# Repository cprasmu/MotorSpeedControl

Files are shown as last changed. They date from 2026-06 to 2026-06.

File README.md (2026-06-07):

# ESP32 Motor Speed Control with L298N and IR Sensor

This project uses a motor & gears from a Microsoft Sidewinder force feedback wheels and an ESP32 to control a DC motor via an L298N H-Bridge, reads rotation speed from an IR sensor connected to a slotted wheel on the motor shaft, and serves a simple web interface to control motor direction and speed. The system accounts for an 11-slot encoder wheel and a 35:1 gearbox reduction to display the actual output shaft RPM. Additionally, it features a TFT display for real-time monitoring and an IR remote for wireless control.

## Features

- Continuous motor control (direction and speed) via web interface
- Precise position control: rotate output shaft exactly one turn clockwise or counterclockwise
- Real-time RPM display of output shaft (after gearbox reduction)
- WiFi access point for easy connection
- Real-time monitoring via TFT display (speed, gear ratio, RPM, direction)
- Wireless control using IR remote (Apple protocol) for motor direction, speed, and preset turns

## Hardware Connections

### L298N H-Bridge
- **IN1** -> ESP32 GPIO 27
- **IN2** -> ESP32 GPIO 26
- **ENA** (PWM speed control) -> ESP32 GPIO 25
- **GND** -> ESP32 GND
- **Motor power supply** -> Connect to appropriate voltage (e.g., 12V) and GND common with ESP32

### IR Sensor
- **Output** -> ESP32 GPIO 33 (with interrupt)
- **VCC** -> 3.3V or 5V (depending on sensor)
- **GND** -> GND

### Motor
- Connect motor terminals to L298N output terminals (OUT1 and OUT2)

### TFT Display
- **TFT MOSI** -> ESP32 GPIO 19
- **TFT SCLK** -> ESP32 GPIO 18
- **TFT CS** -> ESP32 GPIO 5
- **TFT DC** -> ESP32 GPIO 16
- **TFT RST** -> ESP32 GPIO 23
- **TFT BL** (backlight) -> ESP32 GPIO 4

### IR Remote
- **IR Receiver OUT** -> ESP32 GPIO 32

## Setup

1. Install the ESP32 board in Arduino IDE:
   - Go to File > Preferences
   - Add `https://raw.githubusercontent.com/espressif/arduino-esp32/gh-pages/package_esp32_index.json` to Additional Boards Manager URLs
   - Go to Tools > Board > Boards Manager, search for ESP32 and install

2. Install the required libraries:
   - TFT_eSPI (by Bodmer) - Make sure to copy the provided User_Setup.h to the TFT_eSPI library folder or modify your own to match the pins defined in the code.
   - IRremote (by Armin Joachimsmeyer)

3. Connect your ESP32 to the computer via USB.

4. Select the correct ESP32 board (e.g., "ESP32 Dev Module") and port.

5. Upload the `main.ino` sketch.

6. After uploading, open the Serial Monitor to see the IP address of the ESP32 access point.

7. Connect your computer or phone to the WiFi network:
   - SSID: `ESP32_Motor_Control`
   - Password: `12345678`

8. Open a web browser and navigate to `http://192.168.4.1` (or the IP shown in Serial Monitor).

## Usage

### Continuous Control
- Use the **Forward**, **Backward**, and **Stop** buttons to control motor direction
- Use the slider to adjust motor speed (0-255)
- The **Output Shaft RPM** display shows the actual rotational speed after the 35:1 gearbox reduction

### Precise Position Control
- Click **Rotate Clockwise 1 Turn** to rotate the output shaft exactly one turn clockwise
- Click **Rotate Counterclockwise 1 Turn** to rotate the output shaft exactly one turn counterclockwise
- During rotation, the button text changes to "Rotating..." and reverts after completion

### IR Remote Control
- Use an Apple remote to control the motor:
  - Play/Pause: Start/stop forward motion
  - Menu: Start/stop backward motion
  - Center: Stop motor
  - Volume Up: Increase speed by 1
  - Volume Down: Decrease speed by 1
  - Fast Forward (+10x): Rotate 10 turns clockwise
  - Rewind (-10x): Rotate 10 turns counterclockwise

## How It Works

- The IR sensor on the motor shaft reads the 11-slot encoder wheel
- Each rotation of the motor shaft generates 11 pulses
- With 35:1 gearbox, the output shaft rotates once for every 35 motor shaft rotations
- For precise turns: 
  - One output shaft revolution = 35 motor shaft revolutions
  - One motor shaft revolution = 11 encoder pulses
  - Therefore, one output shaft revolution = 35 × 11 = 385 encoder pulses
- The web interface shows the **output shaft RPM** after accounting for the gearbox reduction
- The TFT display shows real-time motor speed, gear ratio, output shaft RPM, motor shaft RPM, and direction
- The IR remote allows wireless control of the motor using standard Apple remote buttons

## Notes

- The IR sensor reads an 11-slot encoder wheel on the motor shaft
- The system includes a 35:1 gearbox reduction ratio in RPM calculations and position control
- The motor speed is controlled via PWM on GPIO 25. Ensure your L298N ENA pin is connected to a PWM-capable pin.
- The IR sensor uses an interrupt on GPIO 33. Make sure the sensor output is clean; we use INPUT_PULLDOWN.
- For safety, start with low motor speeds and ensure the motor is securely mounted.
- The precise turn functions run in separate FreeRTOS tasks to avoid blocking the web server
- The TFT display uses the TFT_eSPI library with custom pin configuration (see code for details)
- The IR remote uses the IRremote library and expects Apple protocol signals

## Customization

- Change WiFi credentials by modifying `ssid` and `password` variables.
- Change motor control pins by modifying `motorIN1`, `motorIN2`, and `motorPWM`.
- Change IR sensor pin by modifying `irSensorPin`.
- Change IR remote pin by modifying `IR_RECEIVE_PIN`.
- To adjust for different encoder wheels, modify `PULSES_PER_REVOLUTION` in the code.
- To adjust for different gearbox ratios, modify `GEARBOX_RATIO` in the code.
- To change TFT display pins, modify the pin definitions at the top of the code and update the User_Setup.h in the TFT_eSPI library.

## License

This project is open source and available for modification and use.

## user Interface

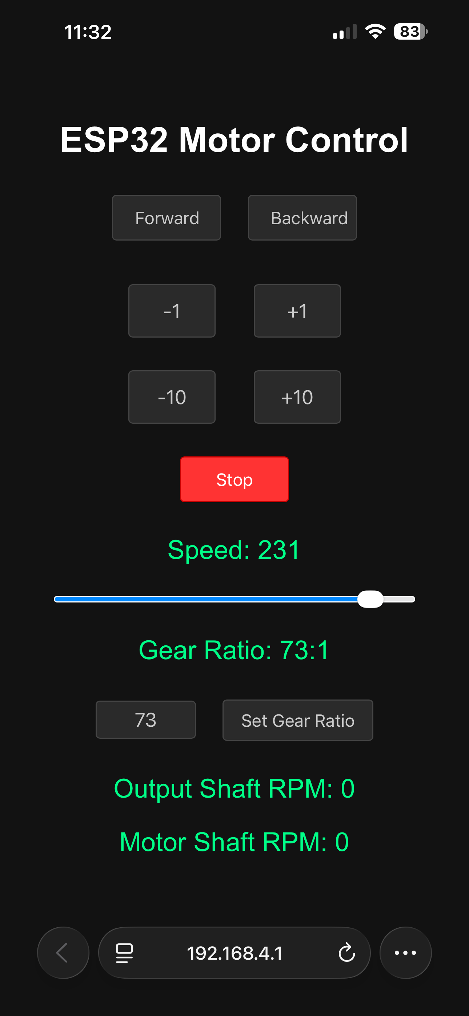
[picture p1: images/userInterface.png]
Assembled View


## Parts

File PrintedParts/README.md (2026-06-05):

# Gearbox Printed parts

These are the files needed to house the gearbox and sensor.

# Additional Parts Required

- 6 M6 X 12 Hex bolt
- 1 M3 x 10 Hex bolt
- 2 M3 x 12 Hex bolt
- 2 M3 Square nut

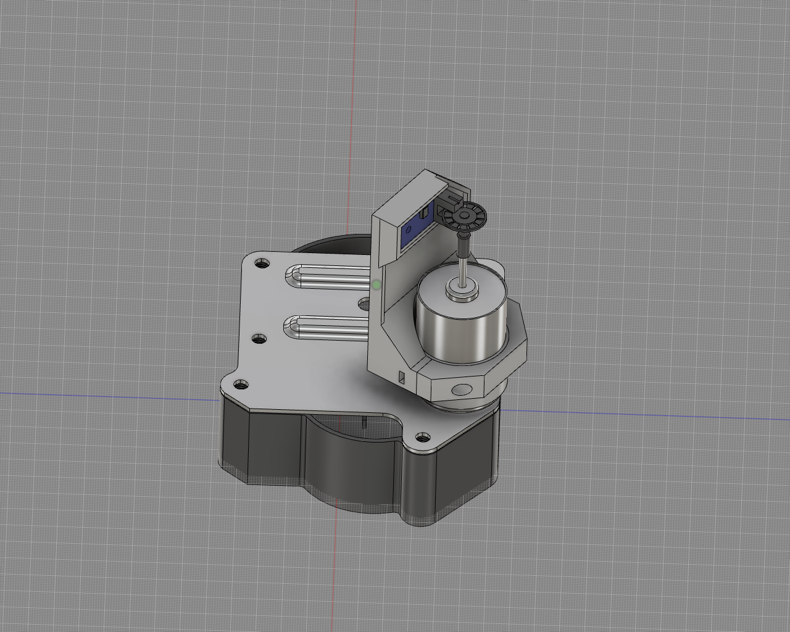
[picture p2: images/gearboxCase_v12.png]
Assembled View


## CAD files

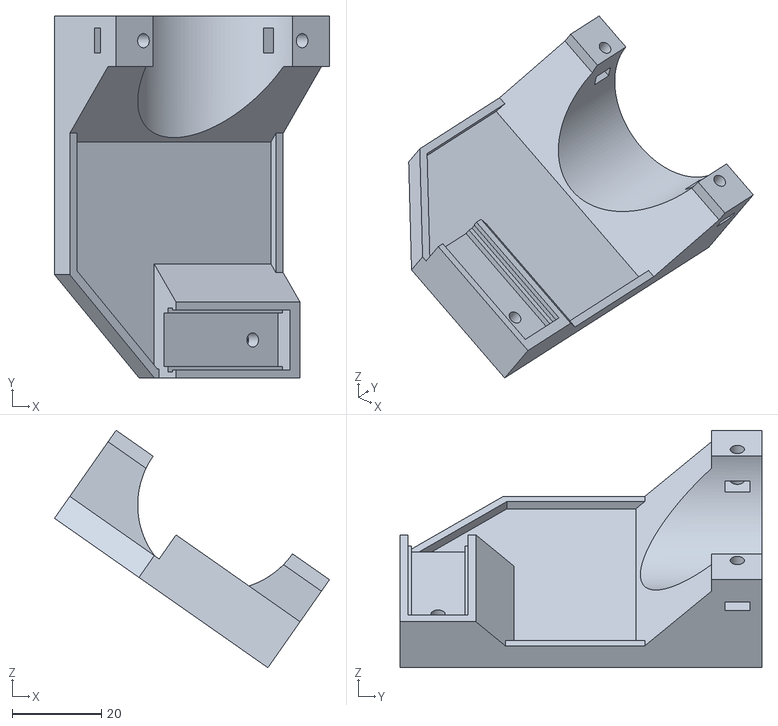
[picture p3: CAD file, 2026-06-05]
PrintedParts/SensorMount.stl
61.8 x 81.2 x 53.3

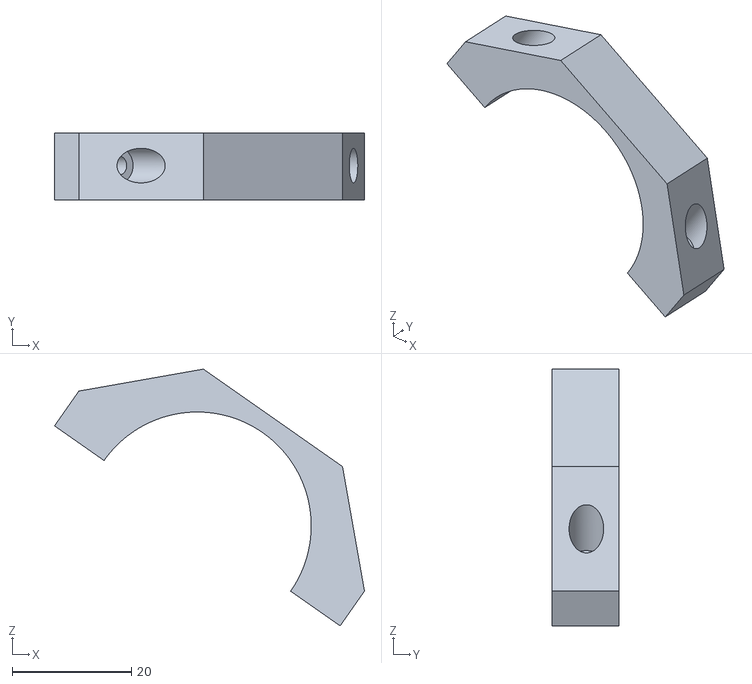
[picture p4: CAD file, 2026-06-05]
PrintedParts/sensorClamp.stl
52.0 x 11.3 x 43.1

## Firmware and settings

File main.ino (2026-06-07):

/*
  Motor Speed Control with ESP32 and L298N H-Bridge
  Reads IR sensor for rotation count
  Serves a web page to control motor speed and direction
  IR Receiver via Apple TV remote (Forward, Backward, Stop, Speed Up, Speed Down, Rotate 10 turns CW/CCW)
  TFT display shows speed, RPM, direction, and gear ratio
  Buttons for manual control (Forward, Backward, Stop, Speed Up, Speed Down)
  Status LEDs indicate motor state (Green for running, Red for stopped)
  FreeRTOS tasks used for non-blocking motor rotation commands from web UI
*/

#define HAS_DISPLAY
#define HAS_REMOTE
#define HAS_BUTTONS
#define HAS_WEB_UI
#define HAS_STATUS_LED

#if defined (HAS_BUTTONS)
  // Button pins
  const int forwardButtonPin = 15;  // Button to move forward
  const int backwardButtonPin = 2; // Button to move backward
  const int stopButtonPin = 17;     // Button to stop motor
  const int speedUpButtonPin = 22; // Button to increase speed
  const int speedDownButtonPin = 21; // Button to decrease speed  
#endif

#if defined (HAS_STATUS_LED)
  // Status LED pins
  const int redLEDPin = 13;   // Red LED for stopped motor
  const int greenLEDPin = 12; // Green LED for running motor
#endif

#if defined (HAS_WEB_UI)
  #include <WiFi.h>
  #include <WebServer.h>
#endif

#include <Arduino.h> // For basic Arduino functions
// FreeRTOS is included by default in ESP32 Arduino core
#include <ESP32Servo.h>

#if defined (HAS_REMOTE)
  #include <IRremote.hpp> // Notice the .hpp extension for newer versions
  const int IR_RECEIVE_PIN = 32; // Digital Pin connected to OUT
#endif

#if defined (HAS_DISPLAY)
  #include <TFT_eSPI.h> // Include TFT_eSPI library for TTGO T-display
  #define USER_SETUP_INFO "User_Setup"
  #define ST7789_DRIVER
  #define TFT_WIDTH  135
  #define TFT_HEIGHT 240
  #define TFT_MOSI 19
  #define TFT_SCLK 18
  #define TFT_CS   5
  #define TFT_DC   16
  #define TFT_RST  23
  #define TFT_BL   4
  #define LOAD_GLCD
  #define LOAD_FONT2
  #define LOAD_FONT4
  #define LOAD_FONT6
  #define LOAD_FONT7
  #define LOAD_FONT8
  #define LOAD_FONT8N
  #define TOUCH_CS -1

  TFT_eSPI tft = TFT_eSPI(); // Create TFT_eSPI object
#endif



#if defined (HAS_WEB_UI)
  // Web server on port 80
  WebServer server(80);

  // WiFi access point credentials
  const char* ssid = "ESP32_Motor_Control";
  const char* password = "12345678";
#endif


// Motor control pins (L298N)
const int motorIN1 = 27; // Direction pin 1
const int motorIN2 = 26; // Direction pin 2
const int motorPWM = 25; // Speed control (PWM)
// IR sensor pin
const int irSensorPin = 33;


// PWM settings
ESP32PWM pwm;
const int pwmFreq = 20000; // 5 kHz PWM frequency
const int pwmResolution = 8; // 8-bit resolution (0-255)

const int delayTime = 10; // Delay time in milliseconds for rotation loops

// Variables for IR sensor counting
volatile long pulseCount = 0;
volatile long lastPulseCount = 0;
unsigned long lastTime = 0;

float rpm = 0.0;          // Output shaft RPM
float motorRpm = 0.0;     // Motor shaft RPM
long pulses = 0; // Declare pulses variable

// Motor state
String motorDirection = "Stop";
volatile int motorSpeed = 200 ; // Start at 200 (range 0-255)

// Encoder and gearbox constants
const int PULSES_PER_REVOLUTION = 11; // 11 slots on the encoder wheel
volatile int GEARBOX_RATIO = 16; // 16:1 reduction gearbox (changeable via web)

// Function to set motor direction and speed
void setMotor(String direction, int speed) {
  // Constrain speed between 0 and 255
  speed = constrain(speed, 0, 255);
  motorSpeed = speed;
  motorDirection = direction;
  
  if (direction == "Forward") {
    digitalWrite(motorIN1, HIGH);
    digitalWrite(motorIN2, LOW);
    #if defined (HAS_STATUS_LED)
      // Motor running - green LED on, red LED off
      digitalWrite(greenLEDPin, HIGH);
      digitalWrite(redLEDPin, LOW);
    #endif
  } else if (direction == "Backward") {
    digitalWrite(motorIN1, LOW);
    digitalWrite(motorIN2, HIGH);
    #if defined (HAS_STATUS_LED)
      // Motor running - green LED on, red LED off
      digitalWrite(greenLEDPin, HIGH);
      digitalWrite(redLEDPin, LOW);
    #endif
  } else { // Stop
    digitalWrite(motorIN1, LOW);
    digitalWrite(motorIN2, LOW);
    speed = 0;
    #if defined (HAS_STATUS_LED)
      // Motor stopped - red LED on, green LED off
      digitalWrite(redLEDPin, HIGH);
      digitalWrite(greenLEDPin, LOW);
    #endif
  }
  pwm.write(speed);
}

// IR sensor interrupt handler
void IRAM_ATTR handleIRSensor() {
  pulseCount = pulseCount + 1;
}

// Function to rotate motor for a specific number of output shaft turns
void rotateMotorTurns(String direction, float turns) {
  // Calculate target pulses: turns * (pulses per motor revolution) * (gear ratio)
  long targetPulses = round(turns * PULSES_PER_REVOLUTION * GEARBOX_RATIO);
   
  // Reset pulse count by storing current value as baseline
  noInterrupts();
  long baselinePulseCount = pulseCount;
  interrupts();
   
  // Set motor direction
  setMotor(direction, motorSpeed);
   
  // Wait until target pulses reached (relative to baseline)
  while (true) {
    noInterrupts();
    long currentPulseCount = pulseCount;
    interrupts();
    
    long pulsesSinceBaseline = currentPulseCount - baselinePulseCount;
    
    if (pulsesSinceBaseline >= targetPulses) {
      break;
    }
    delay(delayTime); // Small delay to prevent watchdog issues
  }
   
  // Stop motor
  setMotor("Stop", motorSpeed);
}

// Function to calculate RPM based on pulses per revolution
// Assuming the slotted wheel has N slots (we'll define PULSES_PER_REVOLUTION)
void calculateRPM() {
  unsigned long now = millis();
  if (now - lastTime >= 250) { // Update every 250ms
    // Disable interrupt temporarily to read pulseCount
    noInterrupts();
    long currentPulseCount = pulseCount;
    long pulses = currentPulseCount - lastPulseCount;
    lastPulseCount = currentPulseCount;
    interrupts();

    // Calculate time interval in seconds
    float timeInSeconds = (now - lastTime) / 1000.0;
    
    // Calculate motor shaft RPM: (pulses * 60) / (pulses per revolution * time in seconds)
    // Pulses per revolution = PULSES_PER_REVOLUTION (11 slots on encoder wheel)
    motorRpm = (pulses * 60.0) / (PULSES_PER_REVOLUTION * timeInSeconds);
    
    // Calculate output shaft RPM after gearbox reduction
    rpm = motorRpm / GEARBOX_RATIO;
  
    lastTime = now;
  }
}
#if defined (HAS_DISPLAY)
void updateDisplay() {

  // Display motor speed
  tft.setTextColor(TFT_WHITE, TFT_BLACK);
  tft.setCursor(0, 0);
  tft.print("Speed: ");
  tft.setTextColor(TFT_CYAN, TFT_BLACK);
  tft.print(motorSpeed);
  tft.print("      ");

  // Display gear ratio
  tft.setTextColor(TFT_WHITE, TFT_BLACK);
  tft.setCursor(0, 25);
  tft.print("Gear: ");
  tft.setTextColor(TFT_CYAN, TFT_BLACK);
  tft.print(GEARBOX_RATIO);
  tft.print(":1");
  tft.print("      ");

  // Display output shaft RPM
  tft.setTextColor(TFT_WHITE, TFT_BLACK);
  tft.setCursor(0, 50);
  tft.print("Out RPM: ");
  tft.setTextColor(TFT_CYAN, TFT_BLACK);
  tft.print((int)rpm);
  tft.print("      ");

  // Display motor shaft RPM
  tft.setTextColor(TFT_WHITE, TFT_BLACK);
  tft.setCursor(0, 75);
  tft.print("Mot RPM: ");
  tft.setTextColor(TFT_CYAN, TFT_BLACK);
  tft.print((int)motorRpm);
  tft.print("      ");
  
  // Display motor direction
  tft.setTextColor(TFT_WHITE, TFT_BLACK);
  tft.setCursor(0, 100);
  tft.print("Dir: ");
 
  if (motorDirection == "Forward") {
    tft.setTextColor(TFT_GREEN, TFT_BLACK);
    tft.print("Forward        ");
  } else if (motorDirection == "Backward") {
    tft.setTextColor(TFT_GREEN, TFT_BLACK);
    tft.print("Backward       ");
  } else {
     tft.setTextColor(TFT_RED, TFT_BLACK);
    tft.print("Stop              ");
  }
}
#endif

#if defined (HAS_WEB_UI)
// HTML web page
const char index_html[] PROGMEM = R"rawliteral(
<!DOCTYPE HTML><html>
<head>
  <title>ESP32 Motor Control</title>
  <meta name="viewport" content="width=device-width, initial-scale=1">
  <style>
    body { 
      font-family: Arial, sans-serif; 
      text-align: center; 
      margin-top: 50px;
      background-color: #121212;
      color: #ffffff;
    }
    .button { 
      padding: 10px 20px; 
      font-size: 16px; 
      margin: 10px; 
      cursor: pointer; 
      background-color: #2a2a2a;
      color: #cccccc;
      border: 1px solid #444444;
      border-radius: 4px;
      width: 100px;
      text-align: center;
    }
    .button:hover {
      background-color: #333333;
    }
    .button:active {
      background-color: #1f1f1f;
    }
    .stop-button {
      background-color: #ff0000;
      border-color: #cc0000;
      color: #ffffff;
    }
    .stop-button:hover {
      background-color: #ff3333;
    }
    .stop-button:active {
      background-color: #cc0000;
    }
    .slider { 
      width: 80%; 
      background: #1f1f1f;
    }
    .speed-display, .rpm-display, .gear-display { 
      font-size: 24px; 
      margin: 20px;
      color: #00ff88;
    }
    .rotation-button {
      background-color: #2a2a2a;
      color: #cccccc;
      border: 1px solid #444444;
      padding: 12px 24px;
      font-size: 18px;
      margin: 10px;
      cursor: pointer;
      border-radius: 4px;
      min-width: 80px;
    }
    .rotation-button:hover {
      background-color: #333333;
    }
    .rotation-button:active {
      background-color: #1f1f1f;
    }
    .gear-input { 
      width: 80px; 
      text-align: center; 
      font-size: 18px; 
      margin: 10px; 
      padding: 5px;
      background-color: #2a2a2a;
      color: #cccccc;
      border: 1px solid #444444;
      border-radius: 4px;
    }
    .gear-button {
      background-color: #2a2a2a;
      color: #cccccc;
      border: 1px solid #444444;
      padding: 8px 16px;
      font-size: 16px;
      margin: 10px;
      cursor: pointer;
      border-radius: 4px;
    }
    .speed-input { 
      width: 80px; 
      text-align: center; 
      font-size: 18px; 
      margin: 10px; 
      padding: 5px;
      background-color: #2a2a2a;
      color: #cccccc;
      border: 1px solid #444444;
      border-radius: 4px;
    }
    .speed-button {
      background-color: #2a2a2a;
      color: #cccccc;
      border: 1px solid #444444;
      padding: 8px 16px;
      font-size: 16px;
      margin: 10px;
      cursor: pointer;
      border-radius: 4px;
    }
    .gear-button:hover {
      background-color: #333333;
    }
    .gear-button:active {
      background-color: #1f1f1f;
    }
    .button-container {
      margin: 20px 0;
    }
    .button-row {
      display: flex;
      justify-content: center;
      gap: 15px;
      margin: 10px 0;
    }
  </style>
</head>
<body>
  <h1>ESP32 Motor Control</h1>
  <div>
    <button class="button" onclick="sendDirection('Forward')">Forward</button>
    <button class="button" onclick="sendDirection('Backward')">Backward</button>
  </div>
  <div class="button-container">
    <div class="button-row">
      <button class="rotation-button" onclick="sendTurnCCW()">-1</button>
      <button class="rotation-button" onclick="sendTurnCW()">+1</button>
    </div>
    <div class="button-row">
      <button class="rotation-button" onclick="sendTurn10CCW()">-10</button>
      <button class="rotation-button" onclick="sendTurn10CW()">+10</button>
    </div>
    <div class="button-row">
      <button class="button stop-button" onclick="sendDirection('Stop')">Stop</button>
    </div>
  </div>

  <input type="number" min="1" max="255" class="speed-input" id="speedInput" value="200">
  <button class="speed-button" onclick="updateSpeed()">Set Speed</button>
  <input type="number" min="1" max="200" class="gear-input" id="gearInput" value="16">
  <button class="gear-button" onclick="updateGearRatio()">Set Gear Ratio</button>

  <div class="speed-display">Speed: <span id="speedValue">200</span></div>
  <div class="gear-display">Gear Ratio: <span id="gearValue">16</span>:1</div>
  <div class="rpm-display">Output Shaft RPM: <span id="rpmValue">0</span></div>
  <div class="rpm-display">Motor Shaft RPM: <span id="motorRpmValue">0</span></div>

  <script>
    function sendDirection(dir) {
      var xhr = new XMLHttpRequest();
      xhr.open("GET", "/setDirection?dir=" + dir, true);
      xhr.send();
    }

    function updateSpeed() {

      speed = document.getElementById("speedInput").value;
      var xhr = new XMLHttpRequest();
      xhr.open("GET", "/setSpeed?speed=" + speed, true);
      xhr.send();
    }

    function sendTurnCW() {
      var xhr = new XMLHttpRequest();
      xhr.open("GET", "/turnCW", true);
      xhr.send();
      // Show feedback
      this.innerText = "Rotating...";
      setTimeout(() => {
        this.innerText = "+1";
      }, 3000);
    }
    function sendTurnCCW() {
      var xhr = new XMLHttpRequest();
      xhr.open("GET", "/turnCCW", true);
      xhr.send();
      // Show feedback
      this.innerText = "Rotating...";
      setTimeout(() => {
        this.innerText = "-1";
      }, 3000);
    }
    function sendTurn10CW() {
      var xhr = new XMLHttpRequest();
      xhr.open("GET", "/turn10CW", true);
      xhr.send();
      // Show feedback
      this.innerText = "Rotating...";
      setTimeout(() => {
        this.innerText = "+10";
      }, 8000); // Longer timeout for 10 turns
    }
    function sendTurn10CCW() {
      var xhr = new XMLHttpRequest();
      xhr.open("GET", "/turn10CCW", true);
      xhr.send();
      // Show feedback
      this.innerText = "Rotating...";
      setTimeout(() => {
        this.innerText = "-10";
      }, 8000); // Longer timeout for 10 turns
    }
    function updateGearRatio() {
      var gearInput = document.getElementById("gearInput");
      var gearValue = gearInput.value;
      document.getElementById("gearValue").innerText = gearValue;
      
      var xhr = new XMLHttpRequest();
      xhr.open("GET", "/setGearRatio?ratio=" + gearValue, true);
      xhr.send();
      
      // Show feedback
      this.innerText = "Setting...";
      setTimeout(() => {
        this.innerText = "Set Gear Ratio";
      }, 1000);
    }
     // Update all status every 250ms using combined endpoint
     setInterval(function() {
       var xhr = new XMLHttpRequest();
       xhr.onreadystatechange = function() {
         if (this.readyState == 4 && this.status == 200) {
           try {
             var status = JSON.parse(this.responseText);
             document.getElementById("speedValue").innerText = status.speed;
             document.getElementById("rpmValue").innerText = status.rpm;
             document.getElementById("motorRpmValue").innerText = status.motorRpm;
           } catch (e) {
             console.error("Error parsing status JSON:", e);
           }
         }
       };
       xhr.open("GET", "/getStatus", true);
       xhr.send();
     }, 250);
  </script>
</body>
</html>)rawliteral";

// Handle root URL
void handleRoot() {
  server.send_P(200, "text/html", index_html);
}

// Handle direction change
void handleDirection() {
  if (server.hasArg("dir")) {
    String dir = server.arg("dir");
    setMotor(dir, motorSpeed); // Keep current speed
    server.send(200, "text/plain", "Direction set to " + dir);
  } else {
    server.send(400, "text/plain", "Missing direction parameter");
  }
}

// Handle speed change
void handleSetSpeed() {
  if (server.hasArg("speed")) {
    int speed = server.arg("speed").toInt();
    setMotor(motorDirection, speed);
    server.send(200, "text/plain", "Speed set to " + String(speed));
  } else {
    server.send(400, "text/plain", "Missing speed parameter");
  }
}

// Handle speed request
void handleGetSpeed() {
  server.send(200, "text/plain", String((int)motorSpeed));
}

// Handle RPM request
void handleRPM() {
  server.send(200, "text/plain", String((int)rpm));
}

// Handle motor RPM request
void handleMotorRPM() {
  server.send(200, "text/plain", String((int)motorRpm));
}

void handleGetStatus() {
  String json = "{";
  json += "\"speed\":" + String((int)motorSpeed) + ",";
  json += "\"gearboxRatio\":" + String(GEARBOX_RATIO) + ",";
  json += "\"rpm\":" + String((int)rpm) + ",";
  json += "\"motorRpm\":" + String((int)motorRpm) + ",";
  json += "\"motorDirection\":\"" + motorDirection + "\"";
  json += "}";
  server.send(200, "application/json", json);
}

// Handle one turn clockwise request
void handleTurnCW() {
  // Run in a separate task to avoid blocking the web server
  xTaskCreatePinnedToCore(
    [](void* parameter) {
      rotateMotorTurns("Forward", 1.0); // One turn clockwise
      vTaskDelete(NULL);
    },
    "TurnCW",
    4096,
    NULL,
    1,
    NULL,
    0
  );
  server.send(200, "text/plain", "Rotating clockwise 1 turn");
}

// Handle gear ratio change
void handleGearRatio() {
  if (server.hasArg("ratio")) {
    int ratio = server.arg("ratio").toInt();
    // Constrain gear ratio to reasonable values
    ratio = constrain(ratio, 1, 200);
    GEARBOX_RATIO = ratio;
    server.send(200, "text/plain", "Gear ratio set to " + String(ratio) + ":1");
  } else {
    server.send(400, "text/plain", "Missing gear ratio parameter");
  }
}

// Handle one turn counterclockwise request
void handleTurnCCW() {
  // Run in a separate task to avoid blocking the web server
  xTaskCreatePinnedToCore(
    [](void* parameter) {
      rotateMotorTurns("Backward", 1.0); // One turn counterclockwise
      vTaskDelete(NULL);
    },
    "TurnCCW",
    4096,
    NULL,
    1,
    NULL,
    0
  );
  server.send(200, "text/plain", "Rotating counterclockwise 1 turn");
}

// Handle ten turns clockwise request
void handleTurn10CW() {
  // Run in a separate task to avoid blocking the web server
  xTaskCreatePinnedToCore(
    [](void* parameter) {
      rotateMotorTurns("Forward", 10.0); // Ten turns clockwise
      vTaskDelete(NULL);
    },
    "Turn10CW",
    4096,
    NULL,
    1,
    NULL,
    0
  );
  server.send(200, "text/plain", "Rotating clockwise 10 turns");
}

// Handle ten turns counterclockwise request
void handleTurn10CCW() {
  // Run in a separate task to avoid blocking the web server
  xTaskCreatePinnedToCore(
    [](void* parameter) {
      rotateMotorTurns("Backward", 10.0); // Ten turns counterclockwise
      vTaskDelete(NULL);
    },
    "Turn10CCW",
    4096,
    NULL,
    1,
    NULL,
    0
  );
  server.send(200, "text/plain", "Rotating counterclockwise 10 turns");
}
#endif

#if defined (HAS_REMOTE)
void handleIr() {

 if (IrReceiver.decode()) {

  if (IrReceiver.decodedIRData.protocol == APPLE) {
      switch (IrReceiver.decodedIRData.command) {
        case 8: 
          setMotor("Forward", motorSpeed);
          Serial.println("Forward button pressed.");
          break;

        case 7:
          setMotor("Backward", motorSpeed);
          Serial.println("Backward button pressed.");
          break;

        case 93:
          setMotor("Stop", motorSpeed); 
          Serial.println("Stop button pressed.");
          break;

        case 11:
          if (motorSpeed < 253) {
            motorSpeed = motorSpeed + 3;
          }
          Serial.println("Speed up button pressed. New speed: " + String(motorSpeed));
          setMotor(motorDirection, motorSpeed); 
          break;

        case 13:
          if (motorSpeed > 2) {
            motorSpeed = motorSpeed - 3;
          }
          Serial.println("Speed down button pressed. New speed: " + String(motorSpeed));
          setMotor(motorDirection, motorSpeed); 
          break;

        case 94:
          handleTurn10CW();
          Serial.println("Rotate 10 turns clockwise button pressed.");
          break;
  
        case 2:
          handleTurn10CCW();
          Serial.println("Rotate 10 turns counterclockwise button pressed."); 
          break;
      }

    }
    
  }
    // Resume listening for the next signal
    IrReceiver.resume(); 

}
#endif

#if defined (HAS_BUTTONS)
void IRAM_ATTR handleButtonPress() {
    // Read button states (active LOW)
    bool forwardPressed = digitalRead(forwardButtonPin) == LOW;
    bool backwardPressed = digitalRead(backwardButtonPin) == LOW;
    bool stopPressed = digitalRead(stopButtonPin) == LOW;
    bool speedUpPressed = digitalRead(speedUpButtonPin) == LOW;
    bool speedDownPressed = digitalRead(speedDownButtonPin) == LOW;

    // Determine motor direction based on button states
    if (forwardPressed) {
      setMotor("Forward", motorSpeed);
    } else if (backwardPressed) {
      setMotor("Backward", motorSpeed);
    } else if (stopPressed) {
      setMotor("Stop", motorSpeed);
    }

    // Adjust speed based on button presses
    if (speedUpPressed && motorSpeed < 255) {
      motorSpeed += 1; // Increase speed
      setMotor(motorDirection, motorSpeed); // Update motor with new speed
    }
    
    if (speedDownPressed && motorSpeed > 0) {
      motorSpeed -= 1; // Decrease speed
      setMotor(motorDirection, motorSpeed); // Update motor with new speed
    }
}
#endif
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
void loop() {
  #if defined (HAS_WEB_UI)
    server.handleClient();
  #endif
  #if defined (HAS_REMOTE)
    handleIr();
  #endif
  
  #if defined (HAS_DISPLAY)
    updateDisplay(); // Update TFT display
  #endif

  calculateRPM(); // Update RPM every 250ms
}

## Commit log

2026-06-05 add models
    [SensorMount.stl, ServoGearboxssss.stl, sensorClamp.stl]
2026-06-05 rename file
    [ServoGearbox.stl]
2026-06-05 fix wrong model
    [ServoGearbox.stl]
2026-06-06 cleanup and use pwm
2026-06-07 can disable LEDs
2026-06-07 add button code
2026-06-07 serial logging, disable IR LED feedback to fix interrupt issues
    [main.ino]
